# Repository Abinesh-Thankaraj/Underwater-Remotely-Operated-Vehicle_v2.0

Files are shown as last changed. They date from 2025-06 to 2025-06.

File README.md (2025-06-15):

# 🤖 Underwater Remotely Operated Vehicle v2.0

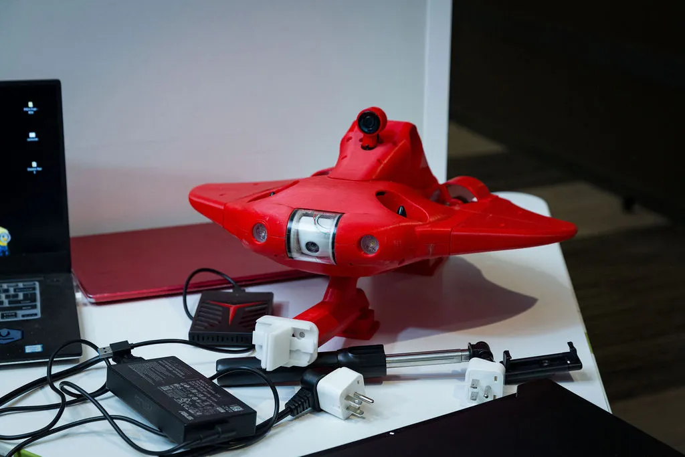
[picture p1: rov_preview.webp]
ROV Preview


A compact and efficient **Underwater Remotely Operated Vehicle (ROV)** designed for search and rescue missions in turbulent water bodies like the Ganga River. This system combines real-time video monitoring and intelligent object detection to support underwater navigation and victim identification.

---

## 🌍 Social Impact & SDG Alignment

This project addresses real-world humanitarian needs and supports multiple **United Nations Sustainable Development Goals (SDGs):**

- ✅ **SDG 3: Good Health and Well-being**  
  Prevents drowning fatalities through faster underwater detection in rescue operations.

- ✅ **SDG 6: Clean Water and Sanitation**  
  Adaptable for underwater inspection of water bodies to support environmental monitoring.

- ✅ **SDG 13: Climate Action**  
  Contributes to climate resilience through flood/disaster recovery and mitigation tools.

> 🎯 This is a high-impact **social innovation project** driven by sustainability, safety, and community well-being.

---

## 🏆 Achievements

- 🥇 **Winners – IEEE R10 International Robotics Competition (Tokyo, Japan)**  
  Presented the ROV v2.0 designed for search and rescue in turbulent water bodies like the Ganga River.

- 🥈 **Runners-up – PALS innoWAH! 2024, IIT Madras (IITM-PALS)**  
  Among 50+ teams selected across India. Developed **ROV v1.0** focused on disaster response and recovery in waterlogged areas.

## 🌟 Key Features
- 🎥 Real-time underwater video feed  
- 🧠 Machine learning-based object detection  
- 🛠️ Custom CAD design and FEA-tested frame  
- 💡 Integrated lighting for murky environments  
- 🤿 Tested in real-world turbulent waters  

---

## 📁 Repository Structure
- `Documentation.zip` – Project report and workflow  
- `Design_3D_Models.zip` – Complete 3D CAD files (STL + source)  
- `Ansys_Report.zip` – Structural and fluid simulation results  
- `New_ROV_Working_Video.zip` – Live footage of version 2.0  
- `Old_ROV_Working_Video.zip` – Early stage test video  
- `TESTING_VIDEOS.zip` – Controlled environment test results  
- `PPT.zip` – Final presentation deck  

---

## 🛠️ Tech Stack
- **Fusion 360 / SolidWorks** – Mechanical design  
- **ANSYS** – Fluid and stress simulations  
- **Python (YOLO)** – Real-time object detection  
- **BlueOS + Pixhawk** – Control system  
- **ROS2 Humble** – Robot middleware and simulation  
- **Git LFS** – For managing large files efficiently  

---

## 🙌 Acknowledgments
Special thanks to mentors and collaborators who supported the development and testing phases of this project.

---

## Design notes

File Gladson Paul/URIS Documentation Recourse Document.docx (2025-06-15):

Contents

1. PROBLEM DEFINITION 2

2. SUSTAINABILITY DEVELOPMENT GOALS 3

a) SDG 11: Sustainable Cities and Communities 3

b) SDG 13: Climate Action 4

c) SDG 6: Clean Water and Sanitation 4

d) SDG 3: Good Health and Well-being 4

e) SDG 9: Industry, Innovation, and Infrastructure 5

f) SDG 14: Life Below Water 5

3. GOVERNMENT ORGANISATIONS 5

4. DESIGN JUSTIFICATION – BIOMIMICRY 6

5. MATERIAL AND BODY DIMENSIONS 7

6. PRESSURE SENSOR 7

7. SONAR 7

MAKE AVERAGE VALUE OF DISASTERS IN A YEAR

URIS Documentation Recourse Document

# 1. PROBLEM DEFINITION

EM_DAT: refer excel: public_emdat,

List_of_topics (https://www.laspositascollege.edu/sitemap.xml)

1. Global Perspective on Disasters

From a total of 17,178 recorded disasters globally, 12,302 (approximately 71.6%) are classified as meteorological and hydrological events. These include disasters such as floods, storms, and mass movements that are primarily water-related. Specifically, 6,012 of these events are flood-related, comprising 66% of all water-based disasters.

In ppt:

From the total recorded disasters globally, approximately 71.6% are classified as meteorological and hydrological events. ~~These include disasters such as floods, storms, and mass movements that are primarily water-related~~. Specifically, 6,012 of these events are flood-related, comprising 66% of all water-based disasters.

2. Asia's Vulnerability to Floods

Asia is significantly impacted by disasters, with 6,876 recorded events in total. Out of these, 1,659 are flood-based, representing 24% of all disasters in the region. Since 2000, the number of disasters in Asia totals 3,957, with flood-related events accounting for 42% of them. This indicates a notable increase in the proportion of flood-related disasters in recent decades.

In ppt:
Asia is significantly impacted with 6,876 recorded events in total. Out of these, 1,659 are flood-based, representing 24% of all disasters in the region. Since 2000, the number of disasters in Asia totals 3,957, with flood-related events accounting for 42% of them.

3. India: A Closer Look

India has recorded a total of 782 disasters, with 327 being flood-based, representing 42% of the total. Since 2000, the number of flood-related disasters has increased to 198, making up 49% of all disasters in the country post-2000.

Types of Floods in India:

General Floods: 1,326

Riverline Floods: 2,024

Coastal Floods: 41

Flash Floods: 707

Glacial Lake Outburst Floods: 4

This results in a total of 4,102 flood events, highlighting the diversity and prevalence of different types of flooding.

4. Human Impact in India Post-2000

The human toll in India due to flood-based disasters after 2000 is staggering:

Deaths: 35,586

Injured: 7,620

Affected Population: 353,403,094

Homeless: 10,383,097

Total Affected: 363,793,811

Total Damage: $1,000,073,680

These figures demonstrate the devastating impact floods have had on India, with 27% of global flood-related deaths occurring in the country, despite India contributing only 5% to the global flood disaster count.

5. Comparative Analysis Post-2000

In India, post-2000, flood-based disasters have accounted for 49% of all disasters. When looking at the broader context of flood impact:

Deaths: 27% of the global total

Injured: 2%

Affected Population: 20%

Homeless: 52% (a significant proportion indicating severe displacement)

Total Affected: 20% of the global total

This data underscores the disproportionate human and economic impact of floods in India compared to other regions.

Conclusion

The analysis reveals that flood-based disasters are a major concern globally, particularly in Asia and India. The increasing frequency and severity of these events post-2000 highlight the need for enhanced disaster management strategies, especially in flood-prone regions like India. With significant percentages of global deaths, injuries, and displacements occurring in India, addressing the causes and effects of floods through better infrastructure, early warning systems, and climate adaptation measures is critical for reducing future risks and impacts.

Recent Events:

a. 2023 Chennai floods (https://en.wikipedia.org/wiki/2023_Chennai_floods), heaving flooding in Chennai (https://en.wikipedia.org/wiki/Chennai) in December 2023 due to Cyclone Michaung (https://en.wikipedia.org/wiki/Cyclone_Michaung).
- Formed 1 December 2023
- Rivers including Cooum and major lakes overflowed in Chennai causing further water logging in the low-lying areas along the banks.
- At least 17 people were killed, and more than 41,000 people were evacuated and temporarily relocated, including 32,158 in Tamil Nadu and 9,500 in Andhra Pradesh.
b. 2023 Thoothukkudi-Tirunelveli floods (https://en.wikipedia.org/w/index.php?title=2023_Thoothukkudi-Tirunelveli_floods&action=edit&redlink=1), heaving flooding in Thoothukkudi (https://en.wikipedia.org/wiki/Thoothukkudi_district) and Tirunelveli (https://en.wikipedia.org/wiki/Tirunelveli_district) districts in December 2023 due to heavy rainfall.
c. 2023 Himalayan floods (https://en.wikipedia.org/wiki/2023_Himalayan_floods) occurred after heavy rain caused flooding and landslides, killing at least 50 people
- Duration August 14, 2023
- 72 people were killed due to the floods.
- at least 700 flooded roads were closed in Himachal Pradesh district.
d. 2021 Uttarakhand flood, flood in Uttarakhand in February 2021 caused by an avalanche from Ronti peak
- Date 18 February 2021
- The disaster left over 200 killed or missing.
- As of May 2021, "83 bodies and 36 human body parts out of a total of 204 people missing have been recovered so far.
e. 2020 Hyderabad floods (https://en.wikipedia.org/wiki/2020_Hyderabad_floods), flash flood in Hyderabad (https://en.wikipedia.org/wiki/Hyderabad) in October 2020 that caused 98 fatalities, a part of the 2020 North Indian Ocean cyclone season (https://en.wikipedia.org/wiki/2020_North_Indian_Ocean_cyclone_season)
- Formed October 11, 2020
- In the first hurricane, 2 people died in Vijayawada, and 50 people died on different parts of Telangana, including 19 in Hyderabad.[21] Additionally, twenty seven people died in Maharashtra, totally 91
- In second hurricane, over 80 people lost their lives and about 40,000 families were displaced.
f. 2024 Persian Gulf floods
- Duration 14 April - 17 April
- In Oman, at least 19 people were killed due to the floods.[15] This included 10 schoolchildren and their driver whose vehicle was washed away by flood waters
- 5 in UAE
- Remnants of the severe thunderstorm system that caused the 2024 Persian Gulf floods affected Pakistan and Afghanistan, killing 700 people.
g. Vetri Duraisamy - Sutlej river
- The search for Vetri Duraisamy after the Sutlej river incident lasted for 9 days
- The National Disaster Response Force (NDRF), along with other teams, conducted extensive search operations before his body was recovered

Here is the consolidated data with main points, including the number of deaths:

1. 2023 Chennai Floods: December 2023 floods from Cyclone Michaung; 17 killed, 41,000+ evacuated in Tamil Nadu and Andhra Pradesh.

2. 2023 Thoothukkudi-Tirunelveli Floods: Heavy December 2023 rainfall caused severe flooding in Thoothukkudi and Tirunelveli districts.

3. 2023 Himalayan Floods: August 2023 floods and landslides killed 72; 700 roads closed in Himachal Pradesh.

4. 2021 Uttarakhand Flood: February 2021 avalanche-induced flood left over 200 dead/missing; 83 bodies recovered by May.

5. 2020 Hyderabad Floods: October 2020 flash floods, part of cyclone season; 98 fatalities, 40,000 families displaced.

6. 2024 Persian Gulf Floods: April 2024 floods killed 19 in Oman, 5 in UAE, and 700 in Pakistan and Afghanistan.

7. Vetri Duraisamy - Sutlej River: NDRF search lasted 9 days before recovering Vetri Duraisamy’s body after river incident.

# 2. SUSTAINABILITY DEVELOPMENT GOALS

[ADD IMAGE]

SDG | NAME | TARGETS
11 | Sustainable Cities and Communities | 11.5
| | 11.B
13 | Climate Action | 13.1
| | 13.2
6 | Clean Water and Sanitation | 6.3
| | 6.6
3 | Good Health and Well-being | 3.6
| | 3.9
9 | Industry, Innovation, and Infrastructure | 9.4
14 | Life Below Water | 14.1
| | 14.2

a) SDG 11: Sustainable Cities and Communities

Goal: Make cities and human settlements inclusive, safe, resilient, and sustainable.

Relevant Targets:

- 11.5: By 2030, significantly reduce the number of deaths and the number of people affected and substantially decrease the direct economic losses relative to global gross domestic product caused by disasters, including water-related disasters, with a focus on protecting the poor and people in vulnerable situations.
  - Project Relevance: The ROV will directly contribute to reducing casualties and economic losses during water-related disasters by improving rescue operations and infrastructure resilience.
- 11.B: By 2020, substantially increase the number of cities and human settlements adopting and implementing integrated policies and plans towards inclusion, resource efficiency, mitigation, and adaptation to climate change, resilience to disasters, and develop and implement, in line with the Sendai Framework for Disaster Risk Reduction 2015-2030, holistic disaster risk management at all levels.
  - Project Relevance: The ROV supports disaster risk management by providing advanced capabilities for underwater inspections and rescue operations.
b) SDG 13: Climate Action

Goal: Take urgent action to combat climate change and its impacts.

Relevant Targets:

- 13.1: Strengthen resilience and adaptive capacity to climate-related hazards and natural disasters in all countries.
  - Project Relevance: The ROV enhances adaptive capacity by enabling rapid response and rescue operations during climate-related disasters such as floods.
- 13.2: Integrate climate change measures into national policies, strategies, and planning.
  - Project Relevance: The use of ROVs in disaster-prone areas can be part of broader climate adaptation strategies and disaster preparedness plans.
c) SDG 6: Clean Water and Sanitation

Goal: Ensure availability and sustainable management of water and sanitation for all.

Relevant Targets:

- 6.3: By 2030, improve water quality by reducing pollution, eliminating dumping, and minimizing the release of hazardous chemicals and materials, halving the proportion of untreated wastewater, and substantially increasing recycling and safe reuse globally.
  - Project Relevance: The ROV can aid in underwater inspections, detecting sources of pollution, and assisting in clean-up operations, contributing to cleaner water bodies.
- 6.6: By 2020, protect and restore water-related ecosystems, including mountains, forests, wetlands, rivers, aquifers, and lakes.
  - Project Relevance: The ROV can help in monitoring and restoring underwater ecosystems affected by pollution or natural disasters.
d) SDG 3: Good Health and Well-being

Goal: Ensure healthy lives and promote well-being for all at all ages.

Relevant Targets:

- 3.6: By 2020, halve the number of global deaths and injuries from road traffic accidents.
  - Project Relevance: The ROV can reduce deaths and injuries caused by water-related accidents, providing timely intervention in rescue operations.
- 3.9: By 2030, substantially reduce the number of deaths and illnesses from hazardous chemicals and air, water, and soil pollution and contamination.
  - Project Relevance: The ROV can assist in detecting underwater pollutants and contaminants that pose a risk to human health, contributing to overall well-being.
e) SDG 9: Industry, Innovation, and Infrastructure

Goal: Build resilient infrastructure, promote inclusive and sustainable industrialization, and foster innovation.

Relevant Targets:

- 9.4: By 2030, upgrade infrastructure and retrofit industries to make them sustainable, with increased resource-use efficiency and greater adoption of clean and environmentally sound technologies and industrial processes, with all countries taking action in accordance with their respective capabilities.
  - Project Relevance: The ROV represents a technological innovation that enhances infrastructure resilience, especially in water-based environments prone to natural disasters.
f) SDG 14: Life Below Water

Goal: Conserve and sustainably use the oceans, seas, and marine resources for sustainable development.

Relevant Targets:

- 14.1: By 2025, prevent and significantly reduce marine pollution of all kinds, in particular from land-based activities, including marine debris and nutrient pollution.
  - Project Relevance: The ROV can assist in detecting and mitigating marine pollution, including identifying and removing debris from water bodies.
- 14.2: By 2020, sustainably manage and protect marine and coastal ecosystems to avoid significant adverse impacts, including by strengthening their resilience, and take action for their restoration to achieve healthy and productive oceans.
  - Project Relevance: The ROV can monitor and support the restoration of underwater ecosystems, contributing to the health of marine environments.

# 3. GOVERNMENT ORGANISATIONS

[ADD IMAGE WITH TEAM]

[ADD IMAGE OF ORGANISATIONS]

Sl. No | METHOD | ORGANISATIONS
1 | Rescue | National Disaster Response Force (NDRF)
| | Indian Navy
| | State Disaster Management Authorities (SDMAs)
| | National Institute of Disaster Management (NIDM)
2 | Monitoring | National Institute of Oceanography (NIO)
| | Central Pollution Control Board (CPCB)
| | Geological Survey of India (GSI)
| | National Remote Sensing Centre (NRSC)
| | Ministry of Environment, Forest and Climate Change (MoEFCC)
3 | Inspection and Maintenance | Inland Waterways Authority of India (IWAI)
| | National Hydroelectric Power Corporation (NHPC)
| | Central Water Commission (CWC)

# 4. DESIGN JUSTIFICATION – BIOMIMICRY

MARINE ANIMAL | ADVANTAGES | DISADVANTAGES | SUITABILITY FOR ROV DESIGN
Dolphin | Streamlined body reduces drag | Complex to replicate mechanically | Moderate: Offers high speed and agility, but complexity and energy use make it less practical for ROV design.
| High maneuverability | High energy consumption for fast swimming
| Echolocation for advanced navigation
Shark | Efficient swimmer with tail propulsion | Lower maneuverability in tight spaces | Moderate: Excellent for endurance and speed, but lower agility and engineering challenges limit its application.
| Endurance for long-distance swimming | Complex skin structure to replicate
| Rough skin reduces drag
Jellyfish | Extremely energy-efficient | Slow speed | Low: Suitable for slow, energy-efficient movement, but lacks the speed and control needed for complex operations.
| Simple design with pulsating movements | Limited control and precision
Stingray | Efficient and quiet movement with undulating fins | Structural complexity in engineering | High: Ideal for ROV design due to balance of speed, efficiency, maneuverability, and engineering feasibility.
| Excellent maneuverability
| Low drag
| Versatile motion from gliding to quick turns
Turtle/Tortoise | Strong, protective shell | Moderate speed | Moderate: Offers stability and durability, but slower speed and high drag can be mitigated for certain ROV applications, making it a reasonable but less optimal choice.
| Stable and steady movement | Limited maneuverability when compared to Stingray
| Good for long-distance travel | High drag from shell shape

# 5. MATERIAL AND BODY DIMENSIONS

Dimensions – Add image and values [2D screen]

MATERIAL | COMPONENTS
PETG | Endcaps
| Propellors
| Sensor Casing
| LED Casing
| Some components inside the Electronics Pipe
PLA | The Main Body

# 6. PRESSURE SENSOR

CONTENT | VALUE
Manufacturer: | TE Connectivity
Pressure Type: | Absolute
Operating Pressure: | 0 bar to 30 bar
Accuracy: | 50 mbar
Interface Type: | I2C
Operating Supply Voltage: | 3 V

# 7. SONAR

[ADD IMAGE OF SONAR SENSORS AND OUTPUT]

Indigenously developed SONAR System only bound by the monetary restrictions

Sonar capable of detecting obstacles for 2 meters in a range of 180 degrees

Not using other sonar systems because of high cost

SONAR | PRICE | PROVIDER
Sonoptix ECHO Multibeam Imaging Sonar | $9,000.00 | BlueRobotics
Ping360 Scanning Imaging Sonar | $2,650.00
Sonar 3D-15 | $ 27,900.00 | Waterlinked
JW Fishers Scanning Sonar Scan-650 | $9,014.00 | Metaldetector.com
MicronSonar | $15,000.00 | TriTech
Panoptix™ PS31 | $1,499.99 | Garmin
Panoptix™ PS70 | $4,799.99

# 8. USBL

The USBL technique works with a transceiver mounted on a ship or surface vessel which sends out acoustic pulses and receives the echoes and a transponder attached to the underwater object which receives the acoustic pulse and sends back a response.

A topside unit (Microcontroller in this case), is used to control the pulses being sent and process the recived data.

The distance is calculated by measuring the distance between the pulses sent and the pulses received along with the speed of sound.

The angle/direction is calculated based on the arrangement of the hydrophones in the transceiver at the surface.

The pulses sent here are of 40 Hz frequency

[ADD IMAGE OF USBL WORKING]

# 9. ELECTRONICS PIPE

The electronics are put in a acrylic pipe of dimension ODxIDxLen.

The Electronic Pipe is sealed on both ends with 3D Printed Endcaps waterproofed with Epoxy Resin. The wires sealed with resin within the endcaps to avoid the water to pass through the wires.

The electronics pipe consist of the following

Sl. No | COMPONENTS
1 | 3D printed parts
2 | 6x 18650 batteries or a pre-made battery pack
3 | ESC 4-in-1
4 | Single ESC
5 | 50A fuse
6 | 2x LED drivers,
7 | Pixhawk flight controller
8 | Raspberry Pi 4
9 | IRF-1404 n-channel MOSFET

[INSERT FLOW DIAGRAM]

# 10. WIRING

Wiring is done using silicone wires because it has more flexibility, durability and it is more resistant to water than normal wires with pvc casing.

# 11. WATER PROOFING

Water proofing is done by different methods in different places

Epoxy Resin

Grease

Acrylite Adhesive

Hot Glue Gun

Soldering

Waterproof Solder Heat Shrink

# 12. BLUEOS

BlueOS is open-source, community-oriented software ecosystem that runs onboard the underwater vehicles and has a connection to the cloud

It provides unified access to tools and services to give a cohesive, welcoming user experience on ROVs and robotic vehicles.

It enables integration with a wide range of sensors inculing, GPS, Sonar, camera, depth sensors, pressure sensors etc.

As an open-source platform, BlueOS allows you to customize and extend the software to meet specific project requirements.

# 13. ARDUSUB

The ArduSub project is a fully-featured open-source solution for remotely operated underwater vehicles (ROVs) and autonomous underwater vehicles (AUVs).

ArduSub has extensive capabilities out of the box including feedback stability control, depth and heading hold, and autonomous navigation.

- Feedback control and stability
- Depth hold
- Heading hold
- Camera Tilt
- Light Control

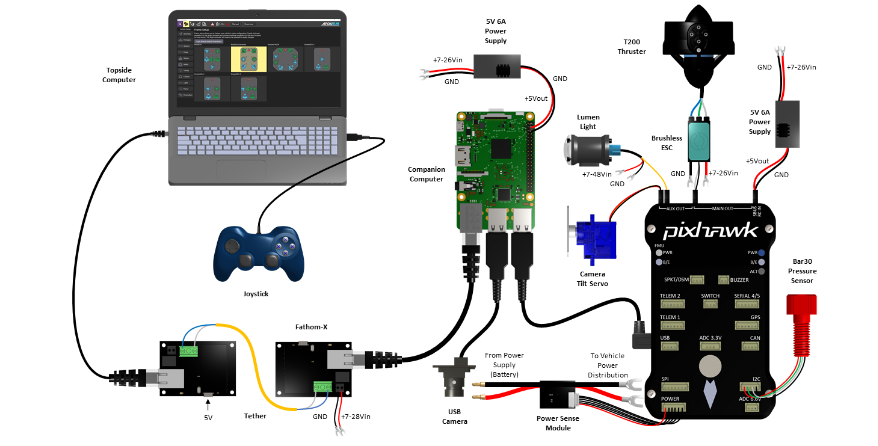
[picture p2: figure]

source (https://www.ardusub.com/introduction/hardware-options/connection-diagrams.html)

# 14. QGROUNDCONTROL

QGroundControl provides full flight control and vehicle setup for PX4 or ArduPilot powered vehicles. It provides easy and straightforward usage for beginners, while still delivering high end feature support for experienced users.

- Full setup/configuration of ArduPilot and PX4 Pro powered vehicles.
- Flight support for vehicles running PX4 and ArduPilot (or any other autopilot that communicates using the MAVLink protocol).
- Mission planning for autonomous flight.
- Flight map display showing vehicle position, flight track, waypoints and vehicle instruments.
- 3D viewer visualizing the 3D map of the environment (.osm file), the 3D model of the vehicle (only multi-rotors for the moment), and the mission 3D trajectory (including the waypoints).
- Video streaming with instrument display overlays.
- Support for managing multiple vehicles.
- QGC runs on Windows, OS X, Linux platforms, iOS and Android devices.

# 15. TETHER

The Underwater robot is tethered using an ethernet cable. Ethernet net cable provides long distance transportation unlike a usb.

It has more buoyancy and durable.

Underwater Robot -- > Topside Computer

Other ways

Underwater Robot -- > wifi -- > Topside Computer

Wireless

Need less wavelength but this compromises the speed

Light based and sound based are costly

# 16. BUOYANCY

The RoV has to have neutral buoyancy. To tackle the weight of the RoV, Buoyancy foam (PU?PS) is added inside the frame to achieve neutral buoyancy.

This enables the RoV to not drown as well as not float.

# 17. END EFFECTORS

The RoV has a robotic arm with customizable end effectors.

This expands the use case of this robot to various domains.

# 18. ASSEMBLY METHOD

The external components such as the motors/properllors, sensors, LED and servos are attached to the 3D printed body

The electronics pipe is placed inside the 3D printed body and the external components are connected to it through the wires coming out of the end caps.

# 19. IMAGE PROCESSING

A image processing AL ML model is included in a web-based interface calibrated to identify humans underwater. Even if the controller in the ground station fails to identify, this image processing model helps/assists the user to identify, even in low light settings.

# 20. MARKET VALUE

In addition, the rise in the demand for underwater drones for defense and security, exploration of deep water offshore oil and gas, and the demand for the product to modernize military forces by the government are the factors driving the market growth.

# 21. COMPETITORS

ATLAS ELEKTRONIK GmbH

Blueye Robotics

Deep Ocean Engineering Inc.

Deep Trekker Inc.

General Dynamics Corporation Company Profile

iBubble

Kongsberg Gruppen ASA

Lockheed Martin Corporation

Oceaneering International Inc.

Saab Seaeye Limited

Teledyne Marine

The Boeing Company Company Profile

Other Key Players

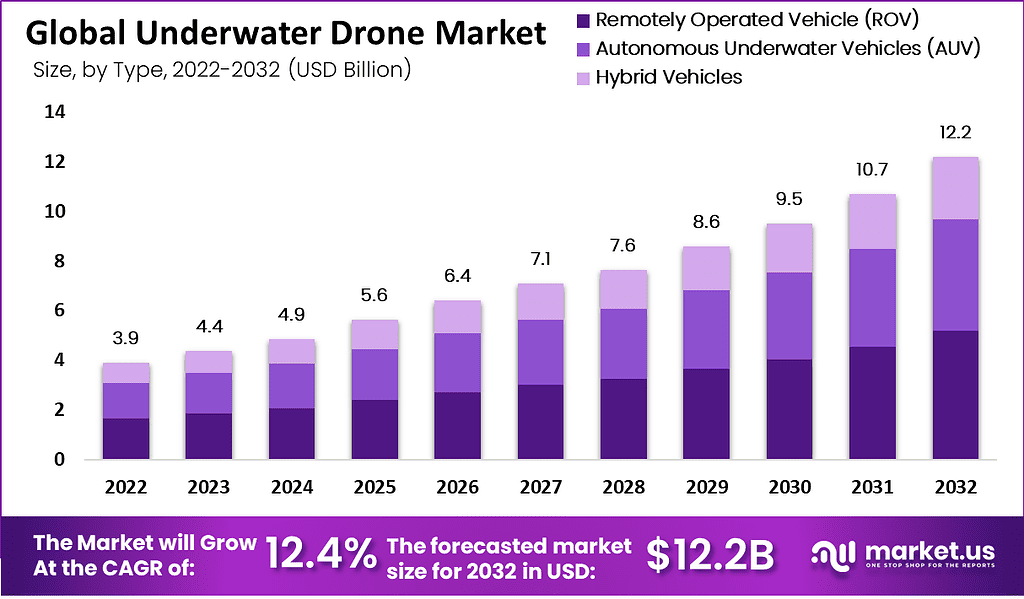
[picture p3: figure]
Underwater Drone Market 1

https://market.us/report/underwater-drone-market/#overview

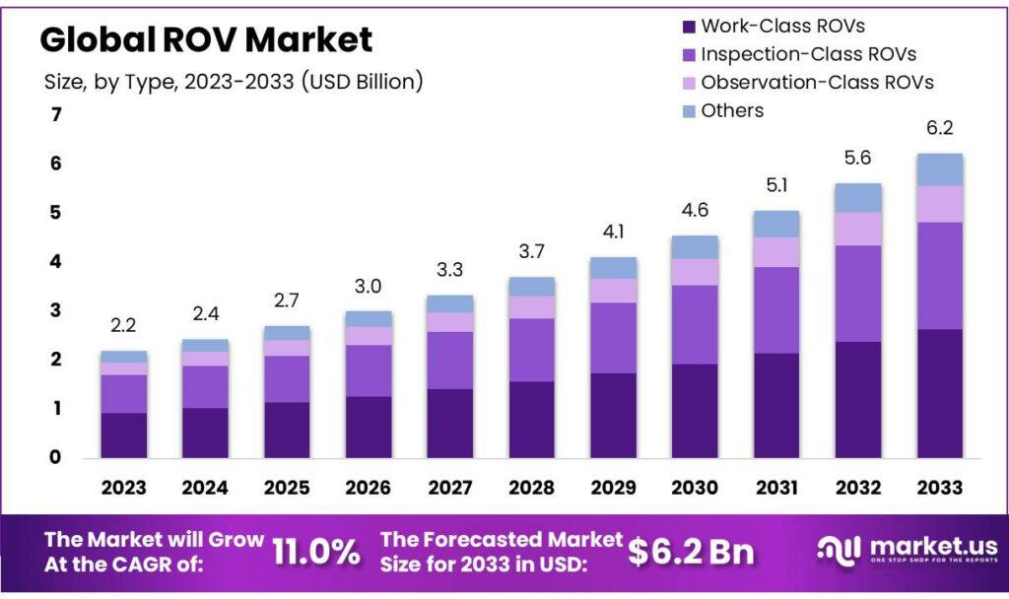
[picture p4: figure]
ROV Market

https://market.us/report/rov-market/

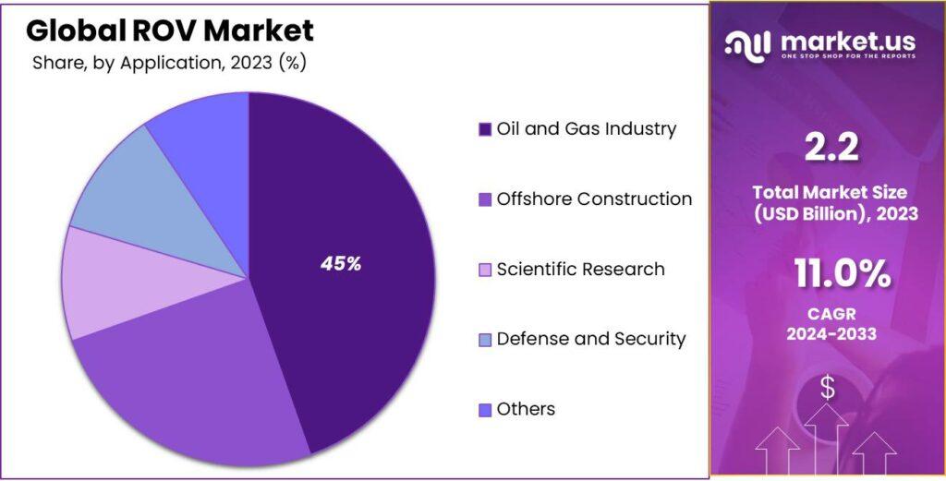
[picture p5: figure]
ROV Market Share

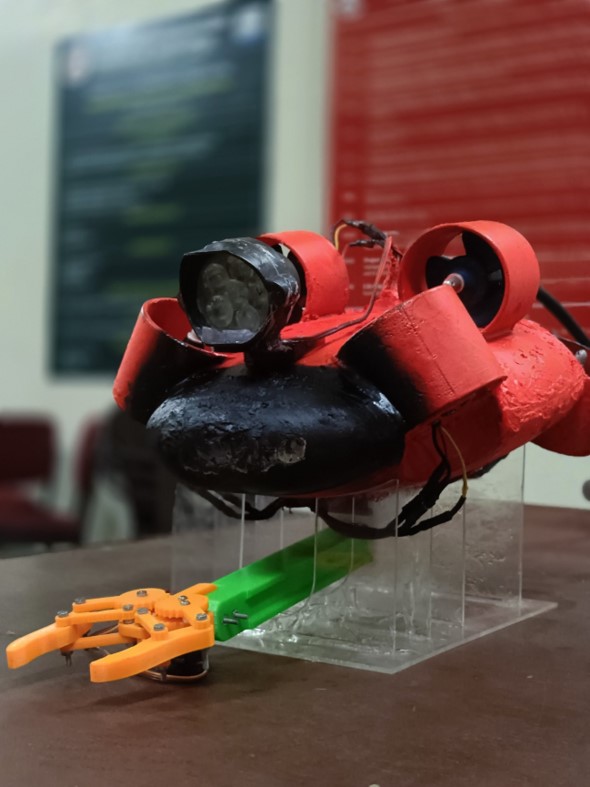
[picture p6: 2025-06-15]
Pictures/Picture1.jpg

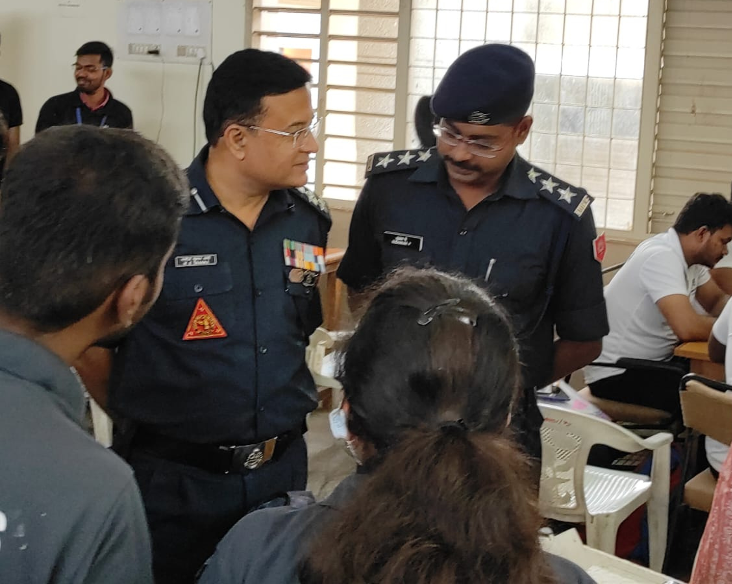
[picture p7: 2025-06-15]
Pictures/NDRF.png

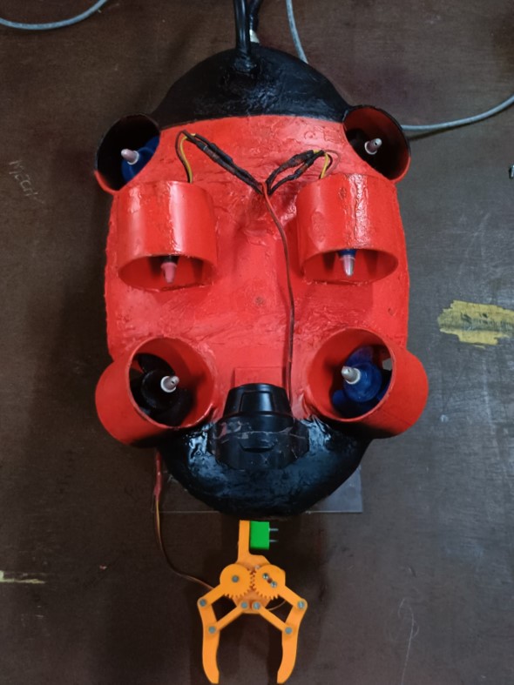
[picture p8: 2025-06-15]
Pictures/Picture3.jpg

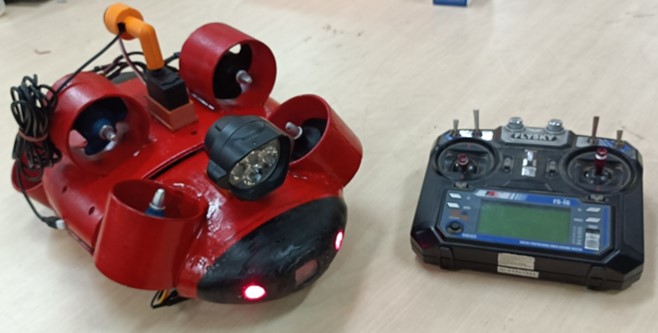
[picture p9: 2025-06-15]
Pictures/Picture2.jpg

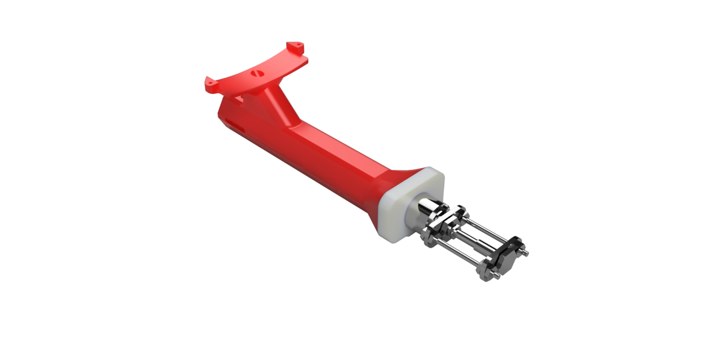
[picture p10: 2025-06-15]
Gladson Paul/render images/End Effectors/eddy current probe.png

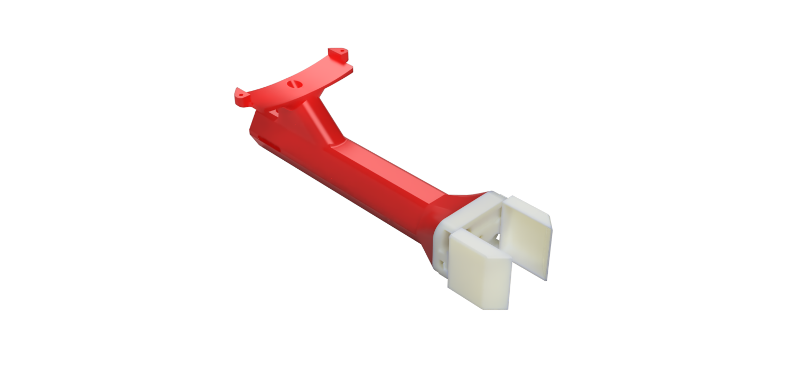
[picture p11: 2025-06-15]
Gladson Paul/render images/End Effectors/Sand sample collector.png

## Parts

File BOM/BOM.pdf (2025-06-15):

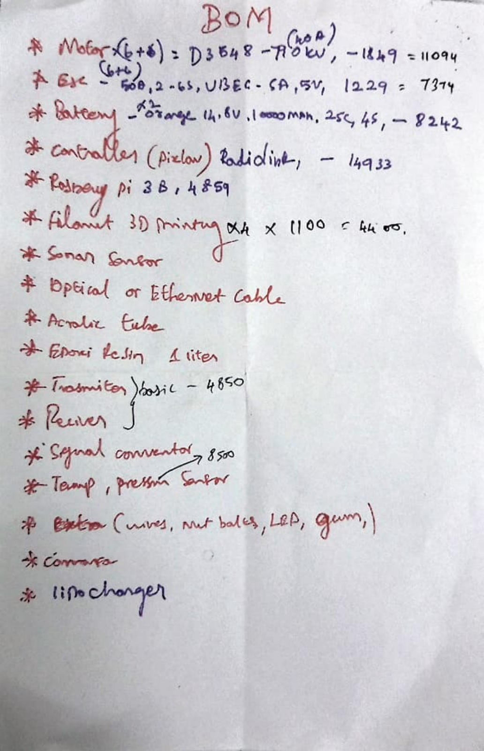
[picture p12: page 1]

Sonan nor

BoM

4850

,-49 |094

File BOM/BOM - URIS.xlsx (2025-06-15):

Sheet: Sheet1
IEEE R10 ROBOTICS COMPETITION 2024 - BOM
UNDERWATER ROBOT FOR INSPECTION AND SALVAGE - URIS
S.No. | COMPONENTS | QUANTITY | COST (INR)
1 | Filament Roll (PLA) | 4 | ₹4400.00
2 | Epoxy Resin (300ml) | 2 | ₹1100.00
3 | Ethernet Cable | 50 m | ₹1450.00 | 29/m
4 | 20 pin connector | 2 | ₹200.00
5 | 18 pin connector | 2 | ₹200.00
6 | Orings (60x5mm) (38x3) | 10 | ₹350.00
7 | Acrylic Pipe | 80x70mm; 250mm | ₹1800.00
 |  | 50x44mm; 50mm | ₹900.00
8 | Camera H-264 (1080p) | 1 | ₹4400.00 |  |  | emale soc
9 | Pixhawk kit | 1 | ₹14231.00
10 | Raspberry Pi 4 model B - 8 GB RAM | 1 | ₹7200.00
11 | Raspberry Pi 4 model B - Heat Sink | 1 | ₹150.00
12 | Pressure Sensor MS5837 | 1 | ₹2200.00
13 | 930kV BLDC Motors | 10 | ₹10730.00
14 | ESC Bi-Directional 30A | 10 | ₹16260.00
15 | SD Card 32 GB Sandisk | 1 | ₹500.00
16 | Light 5W | 2 | ₹300.00
17 | Foam | 2 1/2 m | ₹1200.00
18 | 10 pin water proof | 2 | ₹1500.00
19 | Soldering Flux | 1 | ₹20.00
20 | Glue stick | 10 | ₹100.00
21 | Servo tester | 1 | ₹100.00
22 | Soldering Lead | 40g | ₹120.00
23 | BLS connect | 12 | ₹7200.00
24 |  | 2x20 | ₹350.00
25 | Fuse 60A | 1 | ₹45.00
26 | DC-DC Converter | 3 | ₹150.00
27 | 10kΩ Resistor | 10 | ₹20.00
28 | LED Driver | 2 | ₹258.00
29 | Battery Charger 3S | 1 | ₹2550.00 |  | M3 insert | 50 | 160
30 | PS5 Controller | 1 | ₹7000.00 |  | M4 insert | 50 | 160
31 | Fasteners | As Required | ₹1000.00 |  | Sonar
32 | JST - Connector | 2 | ₹50.00 |  | weighing machine
33 | Red Wire 18 AWG | 20 m | ₹1000.00 | 50/m
 | Black Wire 18 AWG |  | ₹1000.00
34 | Red Wire 14 AWG | 20m | ₹1420.00
 | Black Wire 14 AWG |  | ₹1420.00
TOTAL ( Protoype Cost ) |  |  | ₹92874.00

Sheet: Copy of Sheet1
S.No. | COMPONENTS | QUANTITY | COST (INR)
1 | pvc | 4 | ₹4400.00 | ?
2 | Epoxy Resin (300ml) | 2 | ₹1100.00
4 | 20 pin connector | 2 | ₹200.00
5 | 18 pin connector | 2 | ₹200.00
6 | Orings (60x5mm) (38x3) | 10 | ₹350.00 | ?
7 | Acrylic Pipe | 80x70mm; 250mm | ₹1800.00 | ?
 |  | 50x44mm; 50mm | ₹900.00 | ?
8 | Camera H-264 (1080p) | 1 | ₹4400.00 |  |  | emale soc
9 | Pixhawk kit | 1 | ₹14231.00
10 | Raspberry Pi 4 model B - 8 GB RAM | 1 | ₹7200.00
11 | Raspberry Pi 4 model B - Heat Sink | 1 | ₹150.00
12 | Pressure Sensor MS5837 | 1 | ₹2200.00
13 | 930kV BLDC Motors | 10 | ₹10730.00
14 | ESC Bi-Directional 30A | 10 | ₹16260.00
15 | SD Card 32 GB Sandisk | 1 | ₹500.00 | ?
16 | Light 5W | 2 | ₹300.00
17 | Foam | 2 1/2 m | ₹1200.00
18 | 10 pin water proof | 2 | ₹1500.00
19 | Soldering Flux | 1 | ₹20.00
20 | Glue stick | 10 | ₹100.00
21 | Servo tester | 1 | ₹100.00
22 | Soldering Lead | 40g | ₹120.00
23 | BLS connect | 12 | ₹7200.00
25 | Fuse 60A | 1 | ₹45.00
26 | DC-DC Converter | 3 | ₹150.00
27 | 10kΩ Resistor | 10 | ₹20.00
29 | Battery Charger 3S | 1 | ₹2550.00 |  | M3 insert | 50 | 160
30 | PS5 Controller | 1 | ₹7000.00 |  | M4 insert | 50 | 160
31 | Fasteners | As Required | ₹1000.00 |  | Sonar
32 | JST - Connector | 2 | ₹50.00 |  | weighing machine
33 | Red Wire 18 AWG | 20 m | ₹1000.00 | 50/m
 | Black Wire 18 AWG |  | ₹1000.00
34 | Red Wire 14 AWG | 20m | ₹1420.00
 | Black Wire 14 AWG |  | ₹1420.00
TOTAL ( Protoype Cost ) |  |  | ₹90816.00

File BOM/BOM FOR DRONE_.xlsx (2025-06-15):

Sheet: final
COMPONENTS | PRICE
epoxy resin | 550 |  | 550 | 550 | Asian Paints Woodtech Resin River Kit(300g) |Pack of Resin & Hardener| Self-Levelling Epoxy Resin| Ultra Clear | Safe To Use| Crystal Clear | Deep Resin Molds| Perfect For DIY and Professional Art
PLA FILAMENT 3x | 3300 | 3300 | 3300 | 3300
CABLE | 2000 | 2000 | 4500 | 874 | projexon Fiber Optical Cable 100 m ftth sc 30 (Compatible with LAN, BROADBAND, FTTH, MEDIA CONVTER, GPONE, EPONE, ROUTER, White, One Cable)
SONAR ( WATER PROOF ULTRA SONIC SENSOR) | 3000 | 3000 | 12216 | 12216 | Waterproof Ultrasonic Sensor with Separate Probe
Molex male connector 20pin + pins | 512.89875 | 512.89875 | 512.89875
Molex male connector 18pin + pins | 502.87875 | 502.87875 | 502.87875
2x big oring (60x5mm) | 631.26 | 631.26 | 631.26
2x small oring (38x3mm) | 291.415 | 291.415 | 291.415
acrylic pipe 80x70mm 250mm length | 3589.665 | 3589.665 | 3589.665 | 1800
acrylic pipe 50x44mm 50mm length | 581.16 | 581.16 | 1000 | 1000
Sony IMX323 camera + USB cable | 4666.815 | 4666.815 | 4666.815 | 4349 | Arducam 1080P Low Light Low Distortion USB Camera Module with Microphone
Pressure sensor GY-MS5837 | 1532.225 | 1532.225 | 1532.225 | 430 | GY-63 MS5611-01BA03 High Precision Pressure Sensor Height Sensor Module
3x A2212 motor (930KV) | 2954.295 | 2954.295 | 2954.295 | 2250
2x Sunnysky motor (980KV) | 2788.065 | 2788.065 | 2788.065
12x 5 gram metal weights | 699.73 | 699.73 | 699.73
2x 5W LED on PCB (6000K) | 411.655 | 411.655 | 411.655
2x waterproof LED lens (90 degree) | 85.17 | 85.17 | 85.17
Buoyancy foam (10mm) | 784.9 | 784.9 | 784.9
WEIPU Connector female (WF-16 ZM 10pin) | 397.0425 | 397.0425 | 397.0425
6x 18650 batteries | 3395.945 | 3395.945 | 8999 | 8999 | Orange 11.1V 10000mAh 35C 3S Lithium Polymer Battery Pack
Molex male + female connector 20pin + pins | 512.89875 | 512.89875 | 512.89875
Molex male + female connector 18pin + pins | 502.87875 | 502.87875 | 502.87875
ESC (Emax BLHeli Series 30A ESC with Oneshot) |  | 9756 | 1626 | 1626 | https://robu.in/product/emax-blheli-series-30a-esc-oneshot-original/
Raspberry Pi 3/4B | 9372.04 | 9372.04 | 9372.04 | 3679 | Official Raspberry Pi 3 Model B+
Heatsinks for Raspberry Pi | 227.955 | 227.955 | 227.955
Fuse 60A | 241.315 | 241.315 | 241.315
Pixhawk | 8346.66 | 8346.66 | 14933 | 14933 | Radiolink Pixhawk Flight controller Board
Pixhawk Power module | 657.145 | 657.145 | 657.145 | 602 | APM/Pixhawk Power Module V6.0 Output BEC 3A XT60 Connector 28V 90A
2x LED driver (3W) | 191.215 | 191.215 | 191.215
Micro-SD card 16GB | 554.44 | 554.44 | 554.44
USB type A connector | 177.02 | 177.02 | 177.02
MOSFET IRF1404 | 298.93 | 298.93 | 298.93
Aluminium plate piece (3mm thick) | 420.84 | 420.84 | 420.84
10KΩ resistor | 228.79 | 228.79 | 228.79
WEIPU Connector male (WF-16 TE 10pin) | 528.9725 | 528.9725 | 528.9725
Charger Battery 3S | 1081.325 | 1081.325 | 1081.325
charger cable (4 wire JST-XH) | 254.675 | 254.675 | 254.675
PS4 controller knockoff | 1524.71 | 1524.71 | 1524.71
 | 0 | 0
 | 57246.93 |  | 83747.165
 | 32974

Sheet: Sheet3
epoxy resin | 550
PLA FILAMENT 3x | 3300
CABLE | 4500
SONAR ( WATER PROOF ULTRA SONIC SENSOR) | 12216
Molex male connector 20pin + pins | 512.89875
Molex male connector 18pin + pins | 502.87875
2x big oring (60x5mm) | 631.26
2x small oring (38x3mm) | 291.415
acrylic pipe 80x70mm 250mm length | 3589.665
acrylic pipe 50x44mm 50mm length | 1000
Sony IMX323 camera + USB cable | 4666.815
Pressure sensor GY-MS5837 | 1532.225
3x A2212 motor (930KV) | 2954.295
2x Sunnysky motor (980KV) | 2788.065
12x 5 gram metal weights | 699.73
2x 5W LED on PCB (6000K) | 411.655
2x waterproof LED lens (90 degree) | 85.17
Buoyancy foam (10mm) | 784.9
WEIPU Connector female (WF-16 ZM 10pin) | 397.0425
6x 18650 batteries | 8999
Molex male + female connector 20pin + pins | 512.89875
Molex male + female connector 18pin + pins | 502.87875
ESC 4in1 (25A+) | 9756
ESC 1in1 (20A+) | 632.095
Raspberry Pi 3/4B | 9372.04
Heatsinks for Raspberry Pi | 227.955
Fuse 60A | 241.315
Pixhawk | 14933
Pixhawk Power module | 657.145
2x LED driver (3W) | 191.215
Micro-SD card 16GB | 554.44
USB type A connector | 177.02
MOSFET IRF1404 | 298.93
Aluminium plate piece (3mm thick) | 420.84
10KΩ resistor | 228.79
WEIPU Connector male (WF-16 TE 10pin) | 528.9725
Charger Battery 3S | 1081.325
charger cable (4 wire JST-XH) | 254.675
PS4 controller knockoff | 1524.71
 | 92509.26
 | 184468.52

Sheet: Sheet1
MOTOR
ESC
BATTERY | 6x 18650 batteries OR LIPO
PIXHAWK
RASBERY PI | Official Raspberry Pi 3 Model B+ | 3679.00
PLA FILAMENT
SONAR SENSOR
OPTIACL CABLE, EATHER NET CABLE
ACRALIC TUBE
EPOXI RESIN
TRANSMITER
RECIVER
SIGNAL CONVERTER
TEMPRATURE SENSOR
PRESSUR SENSOR | Pressure sensor GY-MS5837 | 575
CAMARA
FOAM
GUM
FASTNERS
LED
LIPO CHARGER
AURDINO NANO | TZT Nano With the bootloader compatible Nano 3.0 controller for arduino CH340 USB driver 16Mhz Nano v3.0 ATMEGA328P/168P | 150

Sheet: Sheet4
M3x25 +6 M-F standoff | 2x | 3
M3x25 F-F standoff | 1x | 3
M3x6 | 15x | 20
M3x8 | 32x | 35
M3x10 | 11x | 15
M3x12 | 13x | 20
M3x16 | 7x | 10
M3x20 | 3x | 9
M3x25 | 4x | 10
M3x30 | 8x | 10
M3x40 | 2x | 10
M3x50 | 4x | 5
M3 hex nut | 6x | 15
M3nS square nut | 55x | 135
M2 hex nut | 5x | 20
M2x10 | 5x | 10
M2x6 | 4x | 10
M5x16 | 2x | 5
M5 hex nut | 4x | 10
M5nS square nut | 2x | 5

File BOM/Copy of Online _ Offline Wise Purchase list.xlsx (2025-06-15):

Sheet: Combined
ONLINE SOURCES
Sl. No | PRODUCT | QTY | PRICE | PRICE | SUB TOTAL | SHIPPING | TOTAL | WEBSITE | CHECKLIST | COMPLETION
1 | TE Connectivity Board Mount Pressure Sensors MICRO ALTIM. T&R | 2 | 1032.49 | ₹2064.98 | ₹2064.98 | ₹1200.00 | ₹3264.98 | Mouser India | TRUE | TRUE | TO BE DELIVERED | 0
2 | Ceptics India us Converter Plug, India to USA, Japan, Canada & | 2 | ₹469.00 | ₹938.00 | ₹1167.00 | ₹0.00 | ₹1167.00 | Amazon | TRUE | TRUE | DELIVERED | 55
3 | ATOM Digital Kitchen Food Weighing Scale For Healthy | 1 | ₹229.00 | ₹229.00 |  |  |  |  | TRUE
4 | Wizzo 5 Pcs LED Lens With Holder 5 Pcs 3W S... | 1 | ₹214.00 | ₹214.00 | ₹214.00 | ₹0.00 | ₹214.00 | Flipkart | TRUE | TRUE
5 | 0498060.M-LITTELFUSE-0498060.M-Fuse | 2 | ₹38.00 | ₹76.00 | ₹49821.00 |  | ₹49821.00 | Robu | TRUE | TRUE
6 | Arducam 1080P Low Light Low Distortion USB Camera Module with Microphone | 1 | ₹4349.00 | ₹4349.00 |  |  |  |  | TRUE
7 | Raspberry Pi 4 Model-B with 8 GB RAM | 1 | ₹7199.00 | ₹7199.00 |  |  |  |  | TRUE
8 | SanDisk Micro SD/SDHC 32GB Class 10 Memory Card | 1 | ₹449.00 | ₹449.00 |  |  |  |  | TRUE
9 | Aluminum Heat Sink Case with Double Fans for Raspberry Pi 4B - Black | 1 | ₹599.00 | ₹599.00 |  |  |  |  | TRUE
10 | 3 in 1 Aluminum Heat Sink Set for Raspberry Pi 3/4 | 1 | ₹16.00 | ₹16.00 |  |  |  |  | TRUE
11 | SpeedyBee BLS 50A 30x30 4-in-1 ESC | 2 | ₹4049.00 | ₹8098.00 |  |  |  |  | TRUE
12 | Sunny Sky X2212 KV980 Brushless Motors - CW | 3 | ₹1600.00 | ₹4800.00 |  |  |  |  | TRUE
13 | DJI 2212 920KV Brushless DC Motor for Drone with Black Cap (CW Motor Rotation) | 5 | ₹716.00 | ₹3580.00 |  |  |  |  | TRUE
14 | SAMSUNG INR18650-30Q 3000mAh (5c) LI-ION BATTERY | 8 | ₹599.00 | ₹4792.00 |  |  |  |  | TRUE
15 | ISDT Q6 Nano 200W 8A DC Digital Smart 1-6S Li-Po Battery Balance Charger / Discharger | 1 | ₹2999.00 | ₹2999.00 |  |  |  |  | TRUE
16 | UL1007 18AWG PVC Electronic Wire - Red | 15 | ₹23.00 | ₹345.00 |  |  |  |  | TRUE
17 | UL1007 18AWG PVC Electronic Wire - Black | 15 | ₹23.00 | ₹345.00 |  |  |  |  | TRUE
18 | High Quality Ultra Flexible 20AWG Silicone Wire - Red | 15 | ₹21.00 | ₹315.00 |  |  |  |  | TRUE
19 | High Quality Ultra Flexible 14AWG Silicone Wire - Red | 5 | ₹66.00 | ₹330.00 |  |  |  |  | TRUE
20 | High Quality Ultra Flexible 14AWG Silicone Wire - Black | 5 | ₹66.00 | ₹330.00 |  |  |  |  | TRUE
21 | High Quality Ultra Flexible 20AWG Silicone Wire - Green | 15 | ₹21.00 | ₹315.00 |  |  |  |  | TRUE
22 | TowerPro SG90 Servo Motor (180° Rotation)-Good Quality | 4 | ₹146.00 | ₹584.00 |  |  |  |  | TRUE
23 | Cable For Arduino Nano USB A to MINI B (Nickel Plated Connector)-1.2 M | 2 | ₹40.00 | ₹80.00 |  |  |  |  | TRUE
24 | All Purpose Hot Melt Glue Sticks for Glue Gun – 5pcs | 2 | ₹69.00 | ₹138.00 |  |  |  |  | TRUE
25 | Noel Solder Wire 60/40 1.00mm 50gm | 1 | ₹179.00 | ₹179.00 |  |  |  |  | TRUE
26 | Noel FLUX soldering paste-10g-1Pc | 1 | ₹20.00 | ₹20.00 |  |  |  |  | TRUE
27 | Desoldering Wick 1.5m 100 % Copper | 1 | ₹149.00 | ₹149.00 |  |  |  |  | TRUE
28 | 4 Pin JST XH 2.54mm Pitch Plug and Socket with Cable - 5 Pcs. | 1 | ₹56.00 | ₹56.00 |  |  |  |  | TRUE
29 | Gray Flat Ribbon Cable 10 Wires per 1 Meter | 2 | ₹79.00 | ₹158.00 |  |  |  |  | TRUE
30 | Heat Shrink Sleeve 3mm Transparent 3meter Industrial Grade WOER (HST) | 1 | ₹20.00 | ₹20.00 |  |  |  |  | TRUE
31 | Heat Shrink Sleeve 6mm Black 2 Meter Industrial Grade WOER (HST) | 1 | ₹27.00 | ₹27.00 |  |  |  |  | TRUE
32 | Heat Shrink Sleeve 2mm Transparent 3Meter Industrial Grade WOER (HST) | 1 | ₹25.00 | ₹25.00 |  |  |  |  | TRUE
33 | Heat Shrink Sleeve 4mm Transparent 2meter Industrial Grade WOER (HST) | 1 | ₹17.00 | ₹17.00 |  |  |  |  | TRUE
34 | 1.5mm Electrical Waterproof Seal Heat Shrink Splice Wire Sleeve White 4pcs | 6 | ₹84.00 | ₹504.00 |  |  |  |  | TRUE
35 | 3mm Electrical Waterproof Seal Heat Shrink Splice Wire Sleeve White-Red 4pcs | 15 | ₹92.00 | ₹1380.00 |  |  |  |  | TRUE
36 | BMP180 Digital Barometric Sensor Module compatible with Arduino | 2 | ₹37.00 | ₹74.00 |  |  |  |  | TRUE
37 | Male to Male Jumper Wires 40Pcs 20cm | 1 | ₹43.00 | ₹43.00 |  |  |  |  | TRUE
38 | 20CM DuPont Wire Color Jumper Cable 2.54mm 1P-1P Female to Female 40PCS | 1 | ₹36.00 | ₹36.00 |  |  |  |  | TRUE
39 | SpeedyBee SB-F4V3-50-STACK | 1 | ₹6499.00 | ₹6499.00 |  |  |  |  | TRUE
40 | Pro Micro 5V 16M Mini Leonardo Microcontroller Development Board For Arduino | 1 | ₹446.00 | ₹446.00 |  |  |  |  | TRUE
41 | High Quality Ultra Flexible 28AWG Silicone Wire 5m (Red) | 2 | ₹69.00 | ₹138.00 |  |  |  |  | TRUE
42 | Black 1.5M Micro HDMI to, HDMI Copper-Clad Steel, Cable for Raspberry Pi 4B | 1 | ₹108.00 | ₹108.00 |  |  |  |  | TRUE
43 | 3 Pin JST XH 2.54mm Pitch Plug and Socket with Cable - 10 Pcs. | 1 | ₹90.00 | ₹90.00 |  |  |  |  | TRUE
44 | High Quality Ultra Flexible 26AWG Silicone Wire - Blue | 10 | ₹7.00 | ₹70.00 |  |  |  |  | TRUE
45 | Green 3 in 1 Heat Sink Set Aluminum for Raspberry Pi 4B | 1 | ₹43.00 | ₹43.00 |  |  |  |  | TRUE
46 | Waterproof Ultrasonic Obstacle Sensor Range 6 Meters Compatible with Arduino AJ-SR04M | 4 | ₹232.00 | ₹928.00 | ₹928.00 | ₹167.04 | ₹1095.04 | Robokits | TRUE | TRUE
47 | SD1612 - 12Pin Back Nut Connector IP68 Waterproof | 2 | ₹679.45 | ₹1358.90 | ₹1593.92 | ₹356.51 | ₹1950.43 | Sharvielectronics | TRUE | TRUE
48 | 2x20 Pin Dupont Berg Housing 2.54mm Connector | 2 | ₹44.73 | ₹44.73 |  |  |  |  | TRUE
49 | 1x3 Pin Dupont Berg Housing 2.54mm Connector | 20 | ₹45.90 | ₹45.90 |  |  |  |  | TRUE
50 | 1x4 Pin Dupont Berg Housing 2.54mm Connector | 15 | ₹45.90 | ₹45.90 |  |  |  |  | TRUE
51 | Dupont Female Crimp Terminal Contact 20 to 28AWG | 55 | ₹60.16 | ₹60.19 |  |  |  |  | TRUE
52 | Dupont Male Crimp Terminal Contact 20 to 28AWG | 35 | ₹38.30 | ₹38.30 |  |  |  |  | TRUE
53 | Pixhawk PX4 Autopilot 2.4.8 32 Bit Flight Controller kit | 1 | ₹13555 | ₹13555 | ₹13922 |  | ₹13922 | Flyrobo | TRUE | TRUE
54 | Multi Servo Tester, ESC Tester, PPM Generator | 1 | ₹109 | ₹109 |  |  |  |  | TRUE
55 | DC 5V-35V 3W 350mA 700mA LED PWM Dimming Input Driver Module | 2 | 129 | ₹258 |  |  |  |  | TRUE
SUB TOTAL 1 |  |  |  | ₹71434.45
OFFLINE SOURCES
S.No. | MATERIALS | COST (Rs.) | CHECKLIST
1 | PLA + PETG FILLAMENT | ₹5500.00 | TRUE |  | TO PURCHASE | 0
2 | EPOXY RESIN | ₹1100.00 | TRUE |  | PURCHASED | 11
3 | ETHERNET CABLE (37 m) | ₹1450.00 | TRUE
4 | ACRYLIC PIPE | ₹3050.00 | TRUE
5 | AMP FOR USBL | ₹480.00 | TRUE
6 | FASTENERS | ₹1000.00 | TRUE
7 | PS5 CONTROLLER | ₹5900.00 | TRUE
8 | FOAM | ₹1200.00 | TRUE
9 | THREAD LOCKER | ₹50.00 | TRUE
10 | ELECTRONIC ITEMS | ₹340.00 | TRUE
11 | ZIP TIE, KNIFE ,SAND PAPER | ₹1000.00 | TRUE
SUB TOTAL 2 |  | ₹21070.00
TOTAL = SUB TOTAL 1 + SUB TOTAL 2
GRAND TOTAL |  | ₹92504.45

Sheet: Online
Sl. No | PRODUCT | QTY | PRICE | PRICE | SUB TOTAL | SHIPPING | TOTAL | WEBSITE
1 |  | 2 | 1032.49 | ₹2064.98 | ₹2064.98 | ₹1200.00 | ₹3264.98 | Mouser India
2 | Ceptics India us Converter Plug, India to USA, Japan, Canada & | 2 | ₹469.00 | ₹938.00 | ₹1167.00 | ₹0.00 | ₹1167.00 | Amazon
3 | ATOM Digital Kitchen Food Weighing Scale For Healthy | 1 | ₹229.00 | ₹229.00
4 | Wizzo 5 Pcs LED Lens With Holder 5 Pcs 3W S... | 1 | ₹214.00 | ₹214.00 | ₹214.00 | ₹0.00 | ₹214.00 | Flipkart
5 | 0498060.M-LITTELFUSE-0498060.M-Fuse | 2 | ₹38.00 | ₹76.00 | ₹49821.00 |  | ₹49821.00 | Robu
6 | Arducam 1080P Low Light Low Distortion USB Camera Module with Microphone | 1 | ₹4349.00 | ₹4349.00
7 | Raspberry Pi 4 Model-B with 8 GB RAM | 1 | ₹7199.00 | ₹7199.00
8 | SanDisk Micro SD/SDHC 32GB Class 10 Memory Card | 1 | ₹449.00 | ₹449.00
9 | Aluminum Heat Sink Case with Double Fans for Raspberry Pi 4B - Black | 1 | ₹599.00 | ₹599.00
10 | 3 in 1 Aluminum Heat Sink Set for Raspberry Pi 3/4 | 1 | ₹16.00 | ₹16.00
11 | SpeedyBee BLS 50A 30x30 4-in-1 ESC | 2 | ₹4049.00 | ₹8098.00
12 | Sunny Sky X2212 KV980 Brushless Motors - CW | 3 | ₹1600.00 | ₹4800.00
13 | DJI 2212 920KV Brushless DC Motor for Drone with Black Cap (CW Motor Rotation) | 5 | ₹716.00 | ₹3580.00
14 | SAMSUNG INR18650-30Q 3000mAh (5c) LI-ION BATTERY | 8 | ₹599.00 | ₹4792.00
15 | ISDT Q6 Nano 200W 8A DC Digital Smart 1-6S Li-Po Battery Balance Charger / Discharger | 1 | ₹2999.00 | ₹2999.00
16 | UL1007 18AWG PVC Electronic Wire - Red | 15 | ₹23.00 | ₹345.00
17 | UL1007 18AWG PVC Electronic Wire - Black | 15 | ₹23.00 | ₹345.00
18 | High Quality Ultra Flexible 20AWG Silicone Wire - Red | 15 | ₹21.00 | ₹315.00
19 | High Quality Ultra Flexible 14AWG Silicone Wire - Red | 5 | ₹66.00 | ₹330.00
20 | High Quality Ultra Flexible 14AWG Silicone Wire - Black | 5 | ₹66.00 | ₹330.00
21 | High Quality Ultra Flexible 20AWG Silicone Wire - Green | 15 | ₹21.00 | ₹315.00
22 | TowerPro SG90 Servo Motor (180° Rotation)-Good Quality | 4 | ₹146.00 | ₹584.00
23 | Cable For Arduino Nano USB A to MINI B (Nickel Plated Connector)-1.2 M | 2 | ₹40.00 | ₹80.00
24 | All Purpose Hot Melt Glue Sticks for Glue Gun – 5pcs | 2 | ₹69.00 | ₹138.00
25 | Noel Solder Wire 60/40 1.00mm 50gm | 1 | ₹179.00 | ₹179.00
26 | Noel FLUX soldering paste-10g-1Pc | 1 | ₹20.00 | ₹20.00
27 | Desoldering Wick 1.5m 100 % Copper | 1 | ₹149.00 | ₹149.00
28 | 4 Pin JST XH 2.54mm Pitch Plug and Socket with Cable - 5 Pcs. | 1 | ₹56.00 | ₹56.00
29 | Gray Flat Ribbon Cable 10 Wires per 1 Meter | 2 | ₹79.00 | ₹158.00
30 | Heat Shrink Sleeve 3mm Transparent 3meter Industrial Grade WOER (HST) | 1 | ₹20.00 | ₹20.00
31 | Heat Shrink Sleeve 6mm Black 2 Meter Industrial Grade WOER (HST) | 1 | ₹27.00 | ₹27.00
32 | Heat Shrink Sleeve 2mm Transparent 3Meter Industrial Grade WOER (HST) | 1 | ₹25.00 | ₹25.00
33 | Heat Shrink Sleeve 4mm Transparent 2meter Industrial Grade WOER (HST) | 1 | ₹17.00 | ₹17.00
34 | 1.5mm Electrical Waterproof Seal Heat Shrink Splice Wire Sleeve White 4pcs | 6 | ₹84.00 | ₹504.00
35 | 3mm Electrical Waterproof Seal Heat Shrink Splice Wire Sleeve White-Red 4pcs | 15 | ₹92.00 | ₹1380.00
36 | BMP180 Digital Barometric Sensor Module compatible with Arduino | 2 | ₹37.00 | ₹74.00
37 | Male to Male Jumper Wires 40Pcs 20cm | 1 | ₹43.00 | ₹43.00
38 | 20CM DuPont Wire Color Jumper Cable 2.54mm 1P-1P Female to Female 40PCS | 1 | ₹36.00 | ₹36.00
39 | SpeedyBee SB-F4V3-50-STACK | 1 | ₹6499.00 | ₹6499.00
40 | Pro Micro 5V 16M Mini Leonardo Microcontroller Development Board For Arduino | 1 | ₹446.00 | ₹446.00
41 | High Quality Ultra Flexible 28AWG Silicone Wire 5m (Red) | 2 | ₹69.00 | ₹138.00
42 | Black 1.5M Micro HDMI to, HDMI Copper-Clad Steel, Cable for Raspberry Pi 4B | 1 | ₹108.00 | ₹108.00
43 | 3 Pin JST XH 2.54mm Pitch Plug and Socket with Cable - 10 Pcs. | 1 | ₹90.00 | ₹90.00
44 | High Quality Ultra Flexible 26AWG Silicone Wire - Blue | 10 | ₹7.00 | ₹70.00
45 | Green 3 in 1 Heat Sink Set Aluminum for Raspberry Pi 4B | 1 | ₹43.00 | ₹43.00
46 | Waterproof Ultrasonic Obstacle Sensor Range 6 Meters Compatible with Arduino AJ-SR04M | 4 | ₹232.00 | ₹928.00 | ₹928.00 | ₹167.04 | ₹1095.04 | Robokits
47 | SD1612 - 12Pin Back Nut Connector IP68 Waterproof | 2 | ₹679.45 | ₹1358.90 | ₹1593.92 | ₹356.51 | ₹1950.43 | Sharvielectronics
48 | 2x20 Pin Dupont Berg Housing 2.54mm Connector | 2 | ₹44.73 | ₹44.73
49 | 1x3 Pin Dupont Berg Housing 2.54mm Connector | 20 | ₹45.90 | ₹45.90
50 | 1x4 Pin Dupont Berg Housing 2.54mm Connector | 15 | ₹45.90 | ₹45.90
51 | Dupont Female Crimp Terminal Contact 20 to 28AWG | 55 | ₹60.16 | ₹60.19
52 | Dupont Male Crimp Terminal Contact 20 to 28AWG | 35 | ₹38.30 | ₹38.30
53 | Pixhawk PX4 Autopilot 2.4.8 32 Bit Flight Controller kit | 1 | ₹13555 | ₹13555 | ₹13922 |  | ₹13922 | Flyrobo
54 | Multi Servo Tester, ESC Tester, PPM Generator | 1 | ₹109 | ₹109
55 | DC 5V-35V 3W 350mA 700mA LED PWM Dimming Input Driver Module | 2 | 129 | ₹258
SUB TOTAL |  |  |  | ₹71434.45

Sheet: Offline
S.No. | MATERIALS |  | COST (Rs.) | Content | Source | Rep. | Location | Location 2
1 | PLA + PETG FILLAMENT |  | ₹5500.00
2 | EPOXY RESIN |  | ₹1100.00 | 500 g - 1000 g (based on price) | new india traders |  | The New India Trading Company / asian paint dealer in coimbatore/ fosroc dealer in coimbatore (https://maps.app.goo.gl/7gFo7HNiffVZpKNi6)
3 | ETHERNET CABLE |  | ₹1450.00 | 30 m | clg
4 | ACRYLIC PIPE |  | ₹3050.00 | dia - 82 mm x 76 mm, 51 mm x 44 mm | nagendharas , anywhere in nanjapa road |  | Nagendhrass Enginnering Equipments (https://maps.app.goo.gl/myAdnVbDL4RvvbDL6) | The New India Trading Company / asian paint dealer in coimbatore/ fosroc dealer in coimbatore (https://maps.app.goo.gl/7gFo7HNiffVZpKNi6)
5 | AMP FOR USBL |  | ₹480.00 | refer below 2 | karishma | ask kutty bro | Karishma Electronics - Google Maps (https://www.google.com/maps/place/Karishma+Electronics/@10.9972283,76.9560444,17z/data=!3m1!4b1!4m6!3m5!1s0x3ba8590ed2088d63:0x985273ae74f697dd!8m2!3d10.99722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)
6 | FASTENERS |  | ₹1000.00 | refer below 1 | dharmaraja hardware/evergreen traders |  | Dharmaraj Hardwares - Google Search (https://www.google.com/search?sca_esv=1c2a48f6c6fa110b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)
7 | PS5 CONTROLLER |  | ₹5900.00
8 | FOAM |  | ₹1200.00 | polysterene - based on price | anywhere in nanjapa road |  | The New India Trading Company / asian paint dealer in coimbatore/ fosroc dealer in coimbatore (https://maps.app.goo.gl/7gFo7HNiffVZpKNi6)
9 | THREAD LOCKER |  | ₹50.00 | mini | k mart |  | K MART ELECTRICAL AND HARDWARES (https://maps.app.goo.gl/7sqcfaki1wEkWCj5A)
10 | ELECTRONIC ITEMS |  | ₹340.00 | refer below 2 | karishma | ask kutty bro | Karishma Electronics - Google Maps (https://www.google.com/maps/place/Karishma+Electronics/@10.9972283,76.9560444,17z/data=!3m1!4b1!4m6!3m5!1s0x3ba8590ed2088d63:0x985273ae74f697dd!8m2!3d10.99722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)
11 | ZIP TIE, KNIFE ,SAND PAPER |  | ₹1000.00 | 1,1,1 on each(80, 200, 600, 1000) | k mart |  | K MART ELECTRICAL AND HARDWARES (https://maps.app.goo.gl/7sqcfaki1wEkWCj5A)
12 | ORINGS 4 nos each |  | ₹200.00 | Outer dia 76mm Internal Dia 66 mm thickness 5mm, Outer dia 44 mm Internal Dia 38mm thickness 3mm |  |  | The New India Trading Company / asian paint dealer in coimbatore/ fosroc dealer in coimbatore (https://maps.app.goo.gl/7gFo7HNiffVZpKNi6)
SUB TOTAL |  |  | ₹21270.00
 | refer below 1 |  |  | refer below 2 |  |  | The New India Trading Company / asian paint dealer in coimbatore/ fosroc dealer in coimbatore (https://maps.app.goo.gl/7gFo7HNiffVZpKNi6) | Karishma Electronics - Google Maps (https://www.google.com/maps/place/Karishma+Electronics/@10.9972283,76.9560444,17z/data=!3m1!4b1!4m6!3m5!1s0x3ba8590ed2088d63:0x985273ae74f697dd!8m2!3d10.99722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) | K MART ELECTRICAL AND HARDWARES (https://maps.app.goo.gl/7sqcfaki1wEkWCj5A)
 | Content | QTY | QTY | Content | QTY |  | EPOXY RESIN | refer below 2 | THREAD LOCKER
 | M3x25 +6 M-F standoff | 4 | 2x | MOSFET IRF1404 | 2 |  | FOAM |  | ZIP TIE, KNIFE ,SAND PAPER
 | M3x25 F-F standoff | 2 | 1x | 20 pin connector | 2 |  | ORINGS 4 nos each |  | refer below 2
 | M3x6 | 20 | 15x | 20 pin connector pis | 60
2 | M3x8 | 35 | 32x | 5w led with heat sink | 4 |  | Nagendhrass Enginnering Equipments (https://maps.app.goo.gl/myAdnVbDL4RvvbDL6) | Dharmaraj Hardwares - Google Search (https://www.google.com/search?sca_esv=1c2a48f6c6fa110b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)
2 | M3x10 | 15 | 11x | waterproof LED lens | 2 |  | ACRYLIC PIPE | FASTENERS
 | M3x12 | 15 | 13x | usb connector solder type male | 2
4 | M3x16 | 10 | 7x | 10KΩ resistor | 20 |  | RK Electronics
8 | M3x20 | 8 | 3x | HT 60 connector pair | 4 |  | Krishna
4 | M3x25 | 10 | 4x | waterproof mini 3 pin connector | 3 |  | Nanjappa Road
 | M3x30 | 12 | 8x | waterproof mini 2 pin connector | 3 |  | Crimping Tool
 | M3x40 | 5 | 2x | dot board (4x6) | 2
 | M3x50 | 8 | 4x | single stand wire coil | 1
 | M3 hex nut | 10 | 6x | resistor box | 2
 | M3nS square nut | 135 | 55x | IC base 14 pin | 5
 | M2 hex nut | 20 | 5x | screw terminal 2 pin | 2
 | M2x10 | 10 | 5x | 2 pin rmc | 5
 | M2x6 | 10 | 4x | LM 324 | 2
 | M5x16 | 4 | 2x | Female header pins | 5
 | M5 hex nut | 8 | 4x | Twizer 90 deg | 2
 | M5nS square nut | 4 | 2x | Twizer 45 deg | 2
 |  |  |  | White flux | 1
 |  |  |  | Oswal soldering lead | 1
 |  |  |  | Thermal Paste (Heat Paste) | 1
 |  |  |  | Crimping Tool

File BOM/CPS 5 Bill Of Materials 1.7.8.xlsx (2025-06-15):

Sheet: components & 3D prints
 | name 🦒 | cost of a unit ($) 💵 | shipping to US ($) ✈️ | photo 🖼️ | show me the photo!! I want to see the photo!!!!! | primary source | source other 1 | source other 2 | description 📝 |  | Latest update: | added good WEIPU connector source links | added a link for a good battery pack | changed CAT5 ethernet to CAT6, since the quality of the wires is way better, and the cost is only slightly higher | added 1-minute epoxy, which is necessary for epoxying the WEIPU connector in the tether | added a disclaimer about RPi other RAM versions | added one Ali link for the camera | added a caliper to the tool list | added the missing USB A connector | added heatsinks for RPi as well as PETG filament for the RPi mounts (because it deformed because of the heat) | deleted column C "Options" because it was useless anyway | updated ethernet cables & 80mm acrylic pipe yet again | added 2x jumper wire | added BLS connectors and pins, moved charger cable to components | fixed the links for cable braid & PS4 controller | added accurate photos of the propellers | added Bolt Depot as a good source for fasteners
All | CPS 5 | 667.76 | 120.80 | here you go (https://www.instagram.com/cpsdrone/) |  | cpsdrone.com | no | lol | my favourite underwater drone |  |  |  |  |  |  |  |  |  |  |  |  |  |  |  |  |  |  | dup
Frame | print Main front upper |  |  |  | FALSE | - |  |  | Print according to the "3D printing the frame" lesson in the "CHAPTER 3 - Frame of the drone" |  | IMPORTANT INFO: |  |  |  |  |  |  |  |  |  |  |  |  |  |  |  |  | dup
 | print Main front lower |  |  |  | FALSE | - |  |  |  |  | 0. All the components, supplies and tools are required to complete the course, unless said otherwise in the description of the component. |  |  |  |  |  |  |  |  |  |  |  |  |  |  |  |  | dup
 | print Main rear |  |  |  | FALSE | - |  |  |  |  |  |  |  |  |  |  |  |  |  |  |  |  |  |  |  |  |  | dup
 | print Right motor hub |  |  |  | FALSE | - |  |  |  |  | 1. Look at the date in the name of this spreadsheet to see how up to date the links are. |  |  |  | Components are the things used in the drone once or few times at max. (e.g. camera or LEDs) |  | Supplies are things that will end up inside the drone but will be also used over and over again. (e.g. screws, solder, cables) |  | Tools are things that won't end up in the drone, but you use them to make it. (e.g. screwdriver, soldering iron) |  |  |  |  |  |  |  |  | dup
 | print Left motor hub |  |  |  | FALSE | - |  |  |  |  |  |  |  |  |  |  |  |  |  |  |  |  |  |  |  |  |  | dup
 | print Frontback connector |  |  |  | FALSE | - |  |  |  |  | 2. There are checkboxes which are used to enlarge the photo of the component. In order to use them, you will have to create a copy of this spreadsheet on your Google Drive. (Go to File/Make a copy) Keep in mind that your copy won't be updated. |  |  |  |  |  |  |  |  |  |  |  |  |  |  |  |  | dup
 | print Pipe clamp |  |  |  | FALSE | - |  |  |  |  |  |  |  |  |  |  |  |  |  |  |  |  |  |  |  |  |  | dup
 | print Endcapo |  |  |  | FALSE | - |  |  |  |  |  |  |  |  |  |  |  |  |  |  |  |  |  |  |  |  |  | dup
 | print Freshwater module |  |  |  | FALSE | - |  |  |  |  | 3. Go to supplies and tools tabs you see at the bottom to see everything. You'll probably have some of them already. |  |  |  |  |  |  |  |  |  |  |  |  |  |  |  |  | dup
 | print Saltwater module |  |  |  | FALSE | - |  |  |  |  |  |  |  |  |  |  |  |  |  |  |  |  |  |  |  |  |  | dup
Endcaps | print Bottom big basic |  |  |  | FALSE | - |  |  | Print according to the "3D printing the endcaps" lesson in the "CHAPTER 4 - Endcaps" |  | 4. All of the print components - please print them according to the instructions in the "3D printing" lesson in the given chapter. |  |  |  |  |  |  |  |  |  |  |  |  |  |  |  |  | dup
 | print Top big basic |  |  |  | FALSE | - |  |  |  |  |  |  |  |  |  |  |  |  |  |  |  |  |  |  |  |  |  | dup
 | print Bottom big cable |  |  |  | FALSE | - |  |  |  |  | 5. All of the made components - these are the components you are making yourself using other components in other chapters. They are listed since they are essential to the given chapter. |  |  |  |  |  |  |  |  |  |  |  |  |  |  |  |  | dup
 | print Top big cable |  |  |  | FALSE | - |  |  |  |  |  |  |  |  |  |  |  |  |  |  |  |  |  |  |  |  |  | dup
 | print Bottom small gear |  |  |  | FALSE | - |  |  |  |  |  |  |  |  |  |  |  |  |  |  |  |  |  |  |  |  |  | dup
 | print Top small gear |  |  |  | FALSE | - |  |  |  |  |  |  |  |  |  |  |  |  |  |  |  |  |  |  |  |  |  | dup
 | print Bottom small cable |  |  |  | FALSE | - |  |  |  |  |  |  |  |  |  |  |  |  |  |  |  |  |  |  |  |  |  | dup
 | print Top small cable |  |  |  | FALSE | - |  |  |  |  |  |  |  |  |  |  |  |  |  |  |  |  |  |  |  |  |  | dup
 | print Connector holders |  |  |  | FALSE | - |  |  | These are 3 seperate parts printing at the same time. |  |  |  |  |  |  |  |  |  |  |  |  |  |  |  |  |  |  | dup
 | Molex male connector 20pin + pins | 3.38 | 2.76 | #REF! | FALSE | https://www.aliexpress.com/item/2251832653656268.html | https://www.amazon.com/Molex-Circuits-Receptacle-Terminals18-24-Mini-Fit/dp/B079DCBCBZ |  | It's described as "2 Sets 2x10 pin" on Ali |  |  |  |  |  |  |  |  |  |  |  |  |  |  |  |  |  |  | dup
 | Molex male connector 18pin + pins | 3.26 | 2.76 | #REF! | FALSE | https://www.aliexpress.com/item/2251832653656268.html | https://www.amazon.com/Molex-Circuits-Receptacle-Terminals18-24-Mini-Fit/dp/B079DBV2ZL |  | It's described as "2 Sets 2x9 pin" on Ali |  |  |  |  |  |  |  |  |  |  |  |  |  |  |  |  |  |  | dup
 | 2x big oring (60x5mm) | 4.24 | 3.32 | #REF! | FALSE | https://s.click.aliexpress.com/e/_DlgpX4H | https://www.amazon.com/Mr-Ring-5X60-Metric-Viton/dp/B091B9QRPZ |  | It's described as "OD 70mm ID 60mm" on Ali. It's 5mm thick!! You don't need all 10pcs, but you'll just have some spare. |  |  |  |  |  | https://www.allorings.com/configurator-availability | https://www.amazon.in/Oring-ID-5-5-Pack-12pc/dp/B08PTF9KWK |  |  |  |  |  |  |  |  |  |  |  | dup
 | 2x small oring (38x3mm) | 1.46 | 2.03 | #REF! | FALSE | https://s.click.aliexpress.com/e/_DFT835f | https://www.amazon.com/uxcell-Rings-Nitrile-Rubber-Diameter/dp/B07GQXSY9W |  | It's described as "OD 44mm ID 38mm" on Ali. It's 3mm thick!! You don't need all 10pcs, but you'll just have some spare. |  |  |  |  |  |  |  |  |  |  |  |  |  |  |  |  |  |  | dup
 | acrylic pipe 80x70mm 250mm length | 33.00 | 9.99 | #REF! | FALSE | https://www.ebay.com/itm/386381505610 | for some EU countries (https://allegro.pl/oferta/rura-z-pleksi-80mm-5-plexi-pmma-bezbarwna-50cm-12940371668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) | https://s.click.aliexpress.com/e/_Dc8Lb2l | https://www.aliexpress.us/item/3256805668172494.html | Very important! Check the diameter of the pipe immediately after it arrives -> go to "CHAPTER 4 - Endcap" where's the lesson telling you how to do that properly. Preferably you buy 250mm length pipe so you don't have to cut it yourself. If you buy the first option, you may have enough pipe for 2 drones. |  |  |  |  |  |  |  |  |  |  |  |  |  |  |  |  |  | dup
 | (optional if necessary) acrylic pipe 3" x 2.75" 9.84" length | - | - | #REF! | FALSE | local acrylic shop | https://www.amazon.com/KastLite-Acrylic-Diameter-Between-Applications/dp/B09B6VX1C8 | Polycarbonate - not tested (https://www.mscdirect.com/product/details/63406391) | (Not recommended) Since a metric pipe is very hard to find in the US, we have a replacement option which hopefully works as well since 2.75" = 69.85mm ≈ 70mm. Preferably you buy pre-cut 9.84" lenght so you don't have to cut it yourself. |  |  |  |  |  |  |  |  |  |  |  |  |  |  |  |  |  |  | dup
 | acrylic pipe 50x44mm 50mm length | 6.96 | 0.00 | #REF! | FALSE | https://s.click.aliexpress.com/e/_DcZ9IcZ | https://www.ebay.com/itm/183431129501?hash=item2ab558e99d:g:CXYAAOxyyq5TPUZP | https://www.aliexpress.us/item/3256804187624956.html?curPageLogUid=e9W3gsLLqjmN | https://www.aliexpress.us/item/3256805668172494.html | Very important! Check the diameter of the pipe immediately after it arrives -> go to "CHAPTER 4 - Endcap" where's the lesson telling you how to do that properly. Preferably you buy 50mm length pipe so you don't have to cut it yourself. If you buy the first option, you may have enough pipe for 6 drones. |  |  |  |  |  |  |  |  |  |  |  |  |  |  |  |  |  | dup
Camera | print Camera cover |  |  |  | FALSE |  |  |  | Print according to the "3D printing the camera parts" lesson in the "CHAPTER 5 - Camera" |  |  |  |  |  |  |  |  |  |  |  |  |  |  |  |  |  |  | dup
 | print Camera holder |  |  |  | FALSE |  |  |  |  |  |  |  |  |  |  |  |  |  |  |  |  |  |  |  |  |  |  | dup
 | made Small camera pipe |  |  |  | FALSE |  |  |  | Made in the "Endcaps" chapter. |  |  |  |  |  |  |  |  |  |  |  |  |  |  |  |  |  |  | dup
 | Sony IMX323 camera + USB cable | 49.50 | 6.39 | #REF! | FALSE | https://www.aliexpress.us/item/2251832587149808.html?curPageLogUid=h0IKNoc1dhJW | https://www.amazon.com/Microphone-Computer-0-01Lux-Desktop-Facetime/dp/B09WHWMJP8 | https://www.aliexpress.com/item/3256804345985854.html | Pick "L21 (2.1mm)" version. You can try other ones but we have this one. PS: Really important spec of a working camera for the drone is the h.264 compression. Other compression formats won't work. |  |  |  |  |  |  |  |  |  |  |  |  |  |  |  |  |  |  | dup
External components | print Pressure sensor case |  |  |  | FALSE |  |  |  | Print according to the "3D printing the external components parts" lesson in the "CHAPTER 6 - External components" |  |  |  |  |  |  |  |  |  |  |  |  |  |  |  |  |  |  | dup
 | print 2x LED case |  |  |  | FALSE |  |  |  |  |  |  |  |  |  |  |  |  |  |  |  |  |  |  |  |  |  |  | dup
 | print 2x Propeller A2212 (right hand) |  |  |  | FALSE |  |  |  |  |  |  |  |  |  |  |  |  |  |  |  |  |  |  |  |  |  |  | dup
 | print Propeller A2212 (left hand) |  |  |  | FALSE |  |  |  |  |  |  |  |  |  |  |  |  |  |  |  |  |  |  |  |  |  |  | dup
 | print Propeller Sunnysky (right hand) |  |  |  | FALSE |  |  |  |  |  |  |  |  |  |  |  |  |  |  |  |  |  |  |  |  |  |  | dup
 | print Propeller Sunnysky (left hand) |  |  |  | FALSE |  |  |  |  |  |  |  |  |  |  |  |  |  |  |  |  |  |  |  |  |  |  | dup
 | print WEIPU connector part |  |  |  | FALSE |  |  |  |  |  |  |  |  |  |  |  |  |  |  |  |  |  |  |  |  |  |  | dup
 | made Saltwater module |  |  |  | FALSE |  |  |  | It's printed and prepared in the "Frame of the drone" chapter. |  |  |  |  |  |  |  |  |  |  |  |  |  |  |  |  |  |  | dup
 | Pressure sensor GY-MS5837 | 16.98 | 1.37 | #REF! | FALSE | https://s.click.aliexpress.com/e/_DelXMPr | https://www.amazon.com/GY-MS5837-Waterproof-Pressure-Sensor-Module/dp/B09MKL4G1Y |  | Very important! Pick the 30BA option, which works up to 30 bars. The other version is pathetic. |  |  |  |  |  |  |  |  |  |  |  |  |  |  |  |  |  |  | dup
 | 3x A2212 motor (930KV) | 9.54 | 6.77 | #REF! | FALSE | https://s.click.aliexpress.com/e/_DCxYsOl | https://www.amazon.com/Brushless-Outrunner-Professional-Controller-Quadcopter/dp/B08K3GZM2T |  | Pick the 930KV version, 3 motors |  |  |  |  |  |  |  |  |  |  |  |  |  |  |  |  |  |  | dup
 | 2x Sunnysky motor (980KV) | 33.39 | 0.00 | #REF! | FALSE | https://s.click.aliexpress.com/e/_DcYTy0v | slightly faster delivery (https://s.click.aliexpress.com/e/_DDccGIx) | https://s.click.aliexpress.com/e/_DEd4fLL | Pick the "KV980" version, 2 motors |  |  |  |  |  |  |  |  |  |  |  |  |  |  |  |  |  |  | dup
 | 12x 5 gram metal weights | 8.38 | 0.00 | #REF! | FALSE | https://s.click.aliexpress.com/e/_DEcy23n | https://www.amazon.com/Supply-Steel-Stick-Wheel-Weights/dp/B0068EQ9W0 |  | Pick the "Silver" version if you want to have the same ones as we do. (Additionally to 12x5g weights, you'll need about 900g of any small weight, in order to sink the big pipe (80mm one), for the test. You might consider buying more weights just for the purpose of doing these tests. (Look at CHAPTER 4 - Test the endcaps for more info)) |  |  |  |  |  |  |  |  |  |  |  |  |  |  |  |  |  |  | dup
 | 2x 5W LED on PCB (6000K) | 4.30 | 0.63 | #REF! | FALSE | https://s.click.aliexpress.com/e/_DEqdHEt | https://www.amazon.com/Othmro-650-750mA-Aluminum-Heatsink-Integrated/dp/B08221BJD8 | these don't have the pcb board (https://www.aliexpress.com/item/2255800782379856.html) | Somewhat important! Pick the 5W version if you want to shine bright. 10pcs is a lot but you have a replacement in case they overheat. |  |  |  |  |  |  |  |  |  |  |  |  |  |  |  |  |  |  | dup
 | 2x waterproof LED lens (90 degree) | 1.02 | 0.00 | #REF! | FALSE | https://www.aliexpress.us/item/2251832588177575.html?curPageLogUid=JAqGEGGhvaOx | https://s.click.aliexpress.com/e/_DlTtKAv | https://s.click.aliexpress.com/e/_DFcKEU1 | Pick the 90 degrees version. 2 pcs (You can pick 120 degrees too if you feel like having wider lights) |  |  |  |  |  |  |  |  |  |  |  |  |  |  |  |  |  |  | dup
 | Buoyancy foam (10mm) | 4.15 | 5.25 | #REF! | FALSE | https://s.click.aliexpress.com/e/_DDvuIi9 | https://s.click.aliexpress.com/e/_DFa69R7 | https://s.click.aliexpress.com/e/_DlRTvRj | Buy 20x30x2cm, which will require you to slice it later into 1cm thinkness. Alternatively you can try to find buy a version which in 1cm already. Dense polystyrene material. |  |  |  |  |  |  |  |  |  |  |  |  |  |  |  |  |  |  | dup
 | WEIPU Connector female (WF-16 ZM 10pin) | 2.29 | 2.46 | #REF! | FALSE | https://s.click.aliexpress.com/e/_DBMJzL3 | https://s.click.aliexpress.com/e/_DFvEcBJ |  | Buy the "10pin" version, where you get 2 sides, like on the picture. The other side will be useful for a charging cable. |  |  |  |  |  |  |  |  |  |  |  |  |  |  |  |  |  |  | dup
Electronics pipe | print Connector holders |  |  |  | FALSE |  |  |  | These are 3 seperate parts printing at the same time. And yes, you need to print them for the second time for the second chapter. |  |  |  |  |  |  |  |  |  |  |  |  |  |  |  |  |  |  | dup
 | print Small parts |  |  |  | FALSE |  |  |  | Print according to the Electronics pipe chapter, 3D printing lesson. |  |  |  |  |  |  |  |  |  |  |  |  |  |  |  |  |  |  | dup
 | print Big parts |  |  |  | FALSE |  |  |  | Print according to the Electronics pipe chapter, 3D printing lesson. |  |  |  |  |  |  |  |  |  |  |  |  |  |  |  |  |  |  | dup
 | 6x 18650 batteries | 24.88 | 15.79 | #REF! | FALSE | https://s.click.aliexpress.com/e/_Dku5ETj | https://www.tme.com/ux/en-us/details/accu-inr18650-25r/rechargeable-batteries/samsung-sdi/inr-18650-25r/ | warning: bad reviews (I'm in process of finding a better listing) (https://s.click.aliexpress.com/e/_DE29S3V) | Pick 3S2P battery pack. We recommend buying an already assembled battery pack since otherwise you'll need to solder it if you don't have a spot welder and that's not great. If you're buying single cells, find Samsung 30Q, 25R models. 6pcs. |  |  |  |  |  |  |  |  |  |  |  |  |  | Samsung 30Q (https://www.aliexpress.com/item/3256803863550983.html?spm=a2g0o.cart.0.0.fa2938daipFBnS&mp=1) |  |  |  |  | dup
 | Molex male + female connector 20pin + pins | 3.38 | 2.76 | #REF! | FALSE | https://www.aliexpress.com/item/2251832653656268.html | https://www.amazon.com/Molex-Circuits-Receptacle-Terminals18-24-Mini-Fit/dp/B079DCBCBZ |  | It's described as "2 Sets 2x10 pin" on Ali. You will buy the same set of connectors for the second time. This is because they are needed in this chapter seperately as well. |  |  |  |  |  |  |  |  |  |  |  |  |  |  |  |  |  |  | dup
 | Molex male + female connector 18pin + pins | 3.26 | 2.76 | #REF! | FALSE | https://www.aliexpress.com/item/2251832653656268.html | https://www.amazon.com/Molex-Circuits-Receptacle-Terminals18-24-Mini-Fit/dp/B079DBV2ZL |  | It's described as "2 Sets 2x9 pin" on Ali. You will buy the same set of connectors for the second time. This is because they are needed in this chapter seperately as well. |  |  |  |  |  |  |  |  |  |  |  |  |  |  |  |  |  |  | dup
 | BLS connector (Dupont) 2x20 |  |  |  | FALSE | https://s.click.aliexpress.com/e/_DcynHvJ |  |  | Pick "2x20P 10PCS"
 | BLS connector (Dupont) 1x4 |  |  |  | FALSE | https://s.click.aliexpress.com/e/_DcynHvJ | local electronics store |  | Pick "4P 100PCS"
 | 2x BLS connector (Dupont) 1x3 |  |  |  | FALSE | https://s.click.aliexpress.com/e/_DcynHvJ | local electronics store |  | Pick "3P 100PCS". You also get one from the "ESC 1in1"
 | 8x BLS pin female (Dupont) |  |  |  | FALSE | https://s.click.aliexpress.com/e/_DcynHvJ | local electronics store |  | Pick "Female Terminal 100" option
 | ESC 4in1 (25A+) | 23.99 | 0.00 | #REF! | FALSE | https://s.click.aliexpress.com/e/_DdPK3vJ | https://s.click.aliexpress.com/e/_DFZhoo1 | 20A (https://www.amazon.com/Blheli_S-Controller-Racing-Multcopter-Outdoor/dp/B08622C3JC) | Pick the cheaper, 25A version. It's recommended that ESCs are "BLHeli-S" and not "BLHeli-32". Otherwise you'll need to use a different program to reprogram them. |  |  |  |  |  |  |  |  |  |  |  |  |  |  |  |  |  |  | dup
 | ESC 1in1 (20A+) | 7.49 | 0.08 | #REF! | FALSE | https://www.aliexpress.com/item/2255800001568515.html | https://www.amazon.com/Accessories-LittleBee-BLHeli_S-Controller-Support/dp/B089ZTJ7L9 |  | Pick the "1PCS 20A" option. It's recommended that ESCs are "BLHeli-S" and not "BLHeli-32". Otherwise you'll need to use a different program to reprogram them. |  |  |  |  |  |  |  |  |  |  |  |  |  |  |  |  |  |  | dup
 | Raspberry Pi 3/4B | 112.24 | 0.00 | #REF! | FALSE | https://s.click.aliexpress.com/e/_Dm8Adgl | https://www.amazon.com/dp/B07TD43PDZ/ref=twister_B07TN34PCN?_encoding=UTF8&psc=1 |  | Pick the standard 1GB RAM option "RPI 4B-1G". 2GB, 4GB & 8GB versions also work - you may find them cheaper. |  |  |  |  |  |  |  |  |  |  |  |  |  |  |  |  |  |  | dup
 | Heatsinks for Raspberry Pi | 2.73 | 0.00 | #REF! | FALSE | https://s.click.aliexpress.com/e/_DeVxFM1 |  |  | Pick the gold "GD" version because we like gold. Gold is money. |  |  |  |  |  |  |  |  |  |  |  |  |  |  |  |  |  |  | dup
 | Fuse 60A | 0.56 | 2.33 | #REF! | FALSE | https://s.click.aliexpress.com/e/_DCVjoeV |  |  | Pick 1pcs 60A option |  |  |  |  |  |  |  |  |  |  |  |  |  |  |  |  |  |  | dup
 | Pixhawk | 99.96 | 0.00 | #REF! | FALSE | https://s.click.aliexpress.com/e/_DdzQHgN | https://s.click.aliexpress.com/e/_DdTW9Zr |  | Choose the fist version - standard black Pixhawk without any additional components - "Simple Collocation" |  |  |  |  |  |  |  |  |  |  |  |  |  |  |  |  |  |  | dup
 | Pixhawk Power module | 4.74 | 3.13 | #REF! | FALSE | https://s.click.aliexpress.com/e/_DlLL5cl |  |  | Not much to say, only 1pcs |  |  |  |  |  |  |  |  |  |  |  |  |  |  |  |  |  |  | dup
 | 2x LED driver (3W) | 0.82 | 1.47 | #REF! | FALSE | https://www.aliexpress.com/item/2251832638960124.html | https://s.click.aliexpress.com/e/_DB9lwnX |  | Pick the third option even though it's called "Step-down 3W" in the "Color" section. It's not a step-down but it is 3W. (DO NOT pick the version that's actually called "3W LED driver", unless you're in the second link, then the correct one is called "3W LED Driver"). Look at the photo for reference. Let us know if it's too confusing. |  |  |  |  |  |  |  |  |  |  |  |  |  |  |  |  |  |  | dup
 | Micro-SD card 16GB | 4.38 | 2.26 | #REF! | FALSE | https://www.aliexpress.com/item/2255799853816444.html | https://www.amazon.com/SanDisk-2-Pack-microSDHC-Memory-2x32GB/dp/B08GY9NYRM |  | Pick th 16GB version. You can buy it with an adapter if you don't have one already. |  |  |  |  |  |  |  |  |  |  |  |  |  |  |  |  |  |  | dup
 | USB type A connector | 0.87 | 1.25 | #REF! | FALSE | https://s.click.aliexpress.com/e/_DddhMYd | local electronics store |  | The connector need to have easy to access pins for soldering. If you want to buy only one piece I recommend a local electronics store, but Ali is just convenient |  |  |  |  |  |  |  |  |  |  |  |  |  |  |  |  |  |  | dup
 | MOSFET IRF1404 | 1.74 | 1.84 | #REF! | FALSE | https://s.click.aliexpress.com/e/_DFdFQnP | local electronics store |  | If you want to buy only one piece, you can probably buy it in a local electronics store but Ali is convenient. Choose "IRF1404" version. |  |  |  |  |  |  |  |  |  |  |  |  |  |  |  |  |  |  | dup
 | Aluminium plate piece (3mm thick) | 2.93 | 2.11 | #REF! | FALSE | https://s.click.aliexpress.com/e/_DDOBkyp | local hardware store | sth you already have | The dimensions you need are: 3x17x45mm. The plate on Ali is convinient since the dimensions are already similar to what we need, however I still highly recommed just a local hardware store, or something you already have. |  |  |  |  |  |  |  |  |  |  |  |  |  |  |  |  |  |  | dup
 | 10KΩ resistor | 0.42 | 2.32 | #REF! | FALSE | https://s.click.aliexpress.com/e/_Den9DVf | local electronics store |  | If you want to buy only one piece I recommend a local electronics store, but Ali is just convenient |  |  |  |  |  |  |  |  |  |  |  |  |  |  |  |  |  |  | dup
Tether | WEIPU Connector male (WF-16 TE 10pin) | 3.87 | 2.46 | #REF! | FALSE | https://s.click.aliexpress.com/e/_DBDIwPn | https://s.click.aliexpress.com/e/_DC5B4Db | https://www.aliexpress.us/item/3256806414701067.html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: | Choose the "10pin male plug" option, which is the WF-16 TE connector. |  |  |  |  |  |  |  |  |  |  |  |  |  |  |  |  |  |  | dup
 | Charger Battery 3S | 11.93 | 1.02 | #REF! | FALSE | https://s.click.aliexpress.com/e/_DDmmYpP | expensive but very useful charger (https://www.amazon.com/Charger-Battery-Balance-Discharger-Adapter/dp/B07R18YNZQ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) |  |  |  |  |  |  |  |  |  |  |  |  |  |  |  |  |  |  |  |  | dup
 | charger cable (4 wire JST-XH) | 3.05 | 0.00 | #REF! | FALSE | https://s.click.aliexpress.com/e/_DlCAinB |  |  | Pick one "3S 4 wire" version |  |  |  |  |  |  |  |  |  |  |  |  |  |  |  |  |  |  | dup
 | WEIPU Connector male (WF-16 TI 10pin) | - | - | #REF! | FALSE | (bought already earlier in external components) |  |  | You bought this side of the connector earlier in the components chapter section and it's used for the charging cable. |  |  |  |  |  |  |  |  |  |  |  |  |  |  |  |  |  |  | dup
Finishing CPS 5 | PS4 controller knockoff | 18.26 | 0.00 | #REF! | FALSE | (update needed) | https://www.amazon.com/Sony-PlayStation-Dualshock-Wireless-Controller-Black/dp/B00D82Z4YO | https://s.click.aliexpress.com/e/_DBmCelB | We recommend the black version which goes with everything or the red one for a red drone. You can also use an original controller, eg if you have one already. |  |  |  |  |  |  |  |  |  |  |  |  |  |  |  |  |  |  | dup
 | Computer |  |  |  | FALSE |  |  |  | It's your computer but it's quite necessary for operating the drone. |  |  |  |  |  |  |  |  |  |  |  |  |  |  |  |  |  |  | dup
Supplies |  | 154.41 | 35.47 |  | FALSE |  |  |  | These are all of the supplies needed to make the drone summed up. You can see all of them in the second tab on the bottom. |  |  |  |  |  |  |  |  |  |  |  |  |  |  |  |  |  |  | dup
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

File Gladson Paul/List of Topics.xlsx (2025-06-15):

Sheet: Ref. Check List
Sl. No | Topics
1 | Problem
2 | SDG
3 | NDRF and other Organisations
4 | Solution
5 | Design Justification
6 | Material and Body Dimensions
7 | Motors + Propellors
8 | Electrical Pipe
9 | Pressure Sensor
10 | Sonar
11 | USBL
12 | Wiring
13 | Waterproofing
14 | Assembly Method
15 | BlueOS
16 | ArduSub
17 | QGroundControl
18 | Image Processing + Website
19 | Tether
20 | Bouyancy
21 | End Effectors
22 | Comparison with old
23 | Market Comparision
24 | Budget
25 | Power Calculation
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

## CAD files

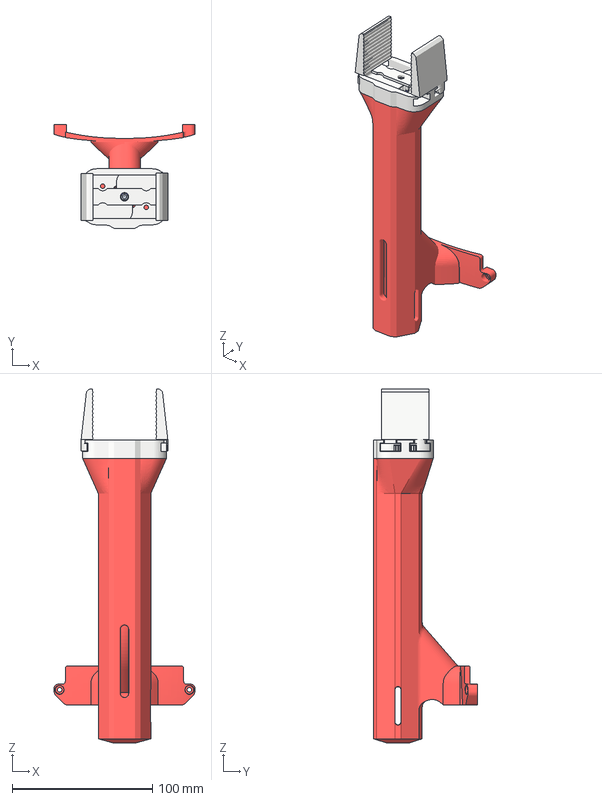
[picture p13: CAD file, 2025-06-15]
Gladson Paul/render images/End Effectors 3D/Gripper (1).3mf
100.5 x 74.0 x 252.6 mm

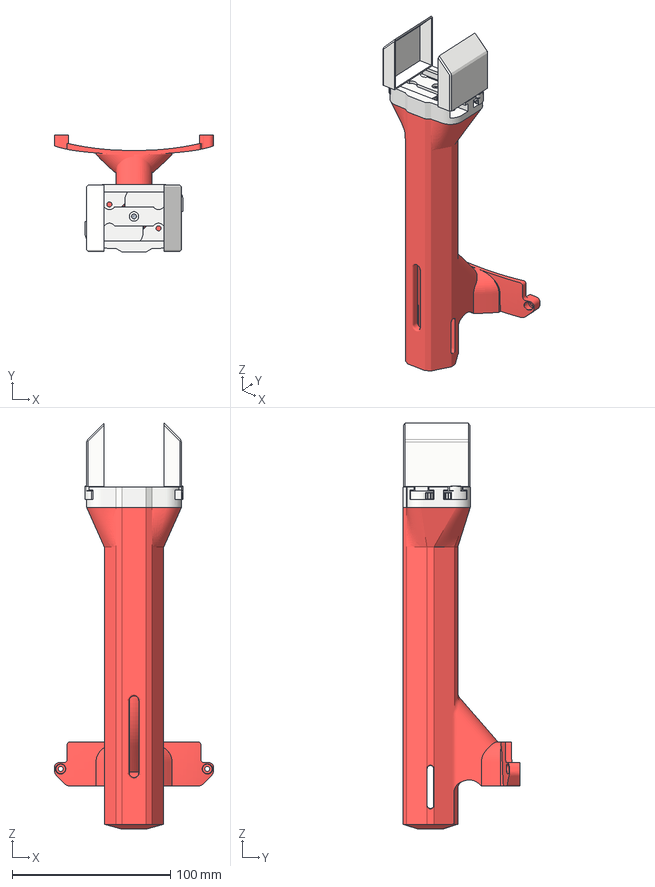
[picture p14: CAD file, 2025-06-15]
Gladson Paul/render images/End Effectors 3D/Sand collector.3mf
100.5 x 74.0 x 256.5 mm

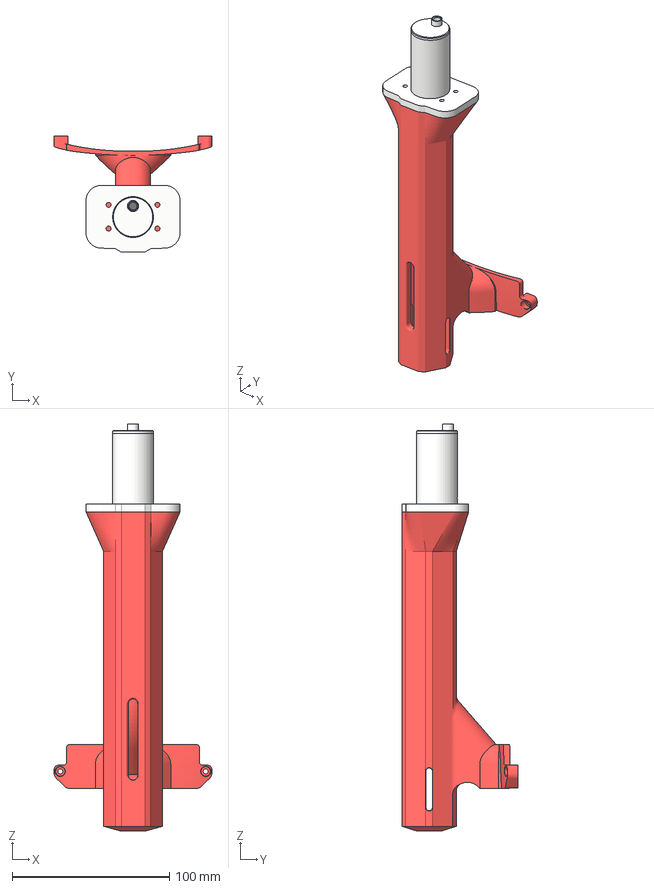
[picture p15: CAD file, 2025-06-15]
Gladson Paul/render images/End Effectors 3D/Water sample collector.3mf
100.5 x 74.0 x 259.1 mm

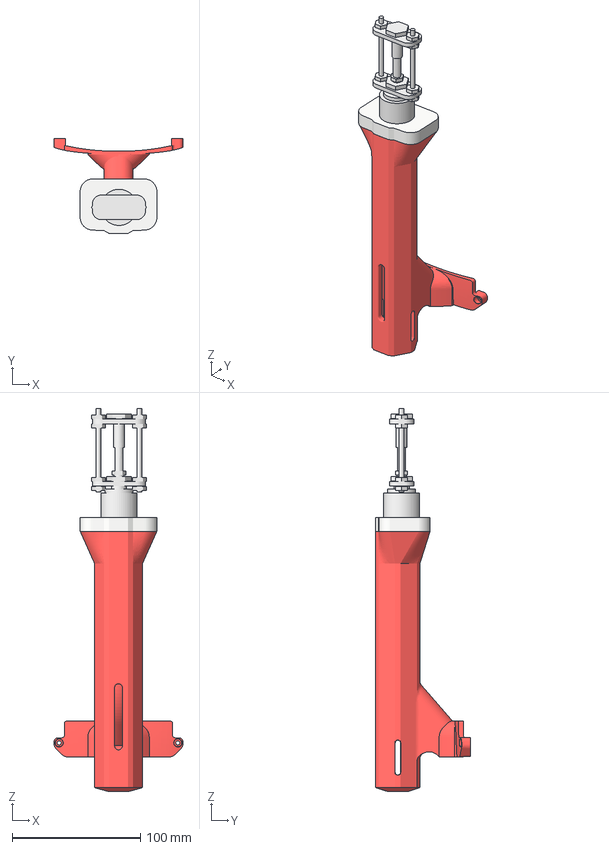
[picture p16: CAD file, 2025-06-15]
Gladson Paul/render images/End Effectors 3D/Corrosion probe.3mf
100.5 x 74.0 x 299.1 mm
